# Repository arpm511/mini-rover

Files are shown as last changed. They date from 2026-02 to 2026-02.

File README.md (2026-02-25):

## Overview

A 6-wheel rocker-bogie rover featuring custom electronics and embedded control systems, built on the **Wild Willy** mechanical design originally created for the [DTU RoboCup](https://robocup.dtu.dk/) stair-climbing challenge.

This project focuses on developing advanced motor control algorithms, power management systems, and autonomous navigation capabilities using modern embedded systems and robotics frameworks.

The rocker-bogie suspension design, inspired by NASA's JPL Martian rovers, enables:
- Independent control of all six wheels
- In-wheel motor mounting for improved weight distribution
- Integrated cable management throughout the arm structure

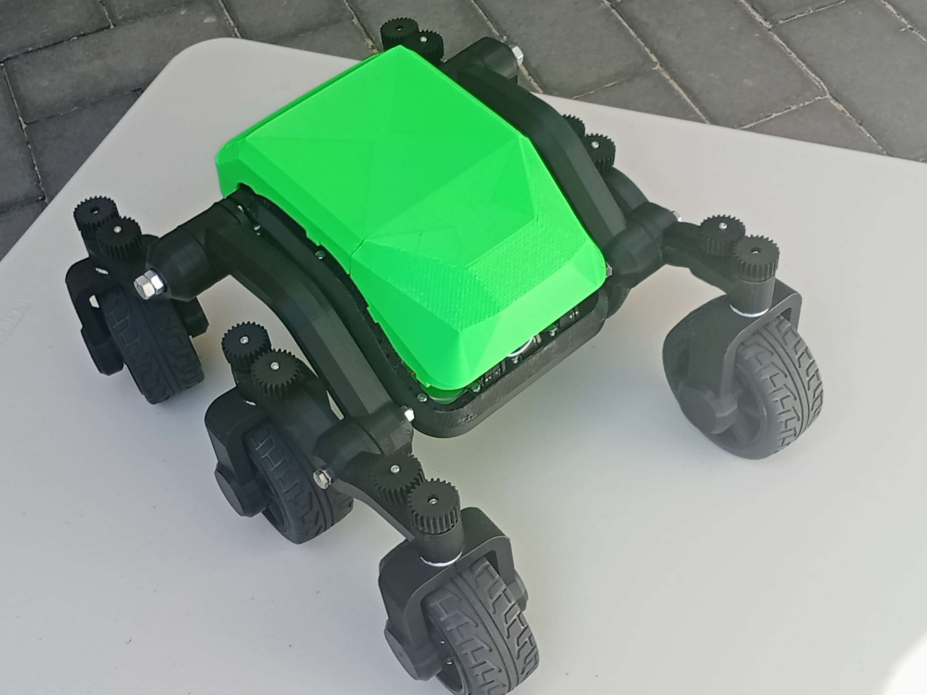
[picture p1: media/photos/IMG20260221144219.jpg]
mini rover photo1


### Project Scope & Attribution

**Original Mechanical Design**: [Wild Willy](https://robocup.dtu.dk/) - 3D printable rocker-bogie chassis, differential systems, and frame structure. The STL files are included in this repository for assembly reference.

**Custom Development Work**:
- **Electronics Design**: Motor driver circuits, power distribution, sensor integration
- **Embedded Software**: Arduino-based PID motor control, encoder feedback systems
- **Control Algorithms**: Speed regulation, differential steering implementation  
- **Future Development**: ROS2 integration for autonomous navigation and SLAM

The differential mechanism between the main arms is housed internally to maximize available mounting space. The frame features mounting points around the perimeter for expansion with additional sensors and systems.

> **Project Status**: Active development. Current implementation includes basic drive systems and manual control. Ongoing work focuses on closed-loop PID motor control and preliminary autonomous navigation capabilities.

## 3D Printing

Look at the file names to determine how many times you need to print each item (e.g 1x_1xm means print one time as-is and one time mirrored).

The largest part is the frame. If it is too large for your printer, consider placing it on the side and diagonally on the bed. An alternative is to split the mesh in two and this way it can also be printed without supports.

All of the parts were printed with the same settings, the only variable being the supports, which for some models are not required:

- Layer height 0.2mm
- Infill: 10%
- Material: PLA
- Printing temperature: Nozzle: 205, Plate: 60, Flow: 100%
- Speed: 80mm/s
- Supports: yes
- Build plate adhesion: Raft 

**Printing parts**

| Qty | Part | Supports | Est. time (per unit) | Total time | Preview | Qty | Part | Supports | Est. time (per unit) | Total time | Preview |
| --- | --- | --- | --- | --- | --- | --- | --- | --- | --- | --- | --- |
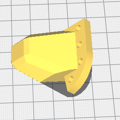
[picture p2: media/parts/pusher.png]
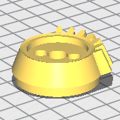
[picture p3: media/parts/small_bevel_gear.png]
| 1x_1xm | pusher | everywhere | 35mins | 1h10m |  | 1x_1xm | small bevel gear | everywhere | 56mins | 1h52m |  |
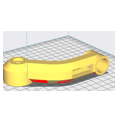
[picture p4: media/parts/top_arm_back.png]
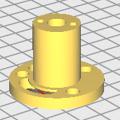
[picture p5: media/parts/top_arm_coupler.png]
| 1x_1xm | top arm back | touching buildplate | 4h40m | ~9h |  | 1x_1xm | Top arm coupler | everywhere | 1h2m | 2h4m |  |
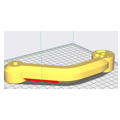
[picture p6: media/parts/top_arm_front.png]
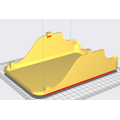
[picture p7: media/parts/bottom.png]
| 1x_1xm | top arm front | touching buildplate | 5h48m | ~12h |  | 1x | bottom | everywhere | 10h17mins | 10h17m |  |
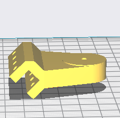
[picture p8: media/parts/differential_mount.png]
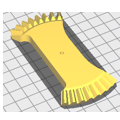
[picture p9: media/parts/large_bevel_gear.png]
| 1x | differential mount | everywhere | 1h28m | 1h28m |  | 1x | large bevel gear | everywhere | 1h24m | 1h24m |  |
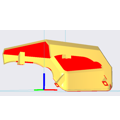
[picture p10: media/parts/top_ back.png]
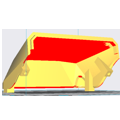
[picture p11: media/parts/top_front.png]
| 1x | top back | everywhere | 8h47m | 8h47m |  | 1x | top front | everywhere | 7h | 7h |  |
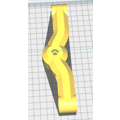
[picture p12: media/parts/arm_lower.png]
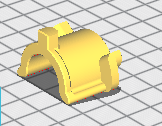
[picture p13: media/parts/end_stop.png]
| 2x | arm lower | touching buildplate | 5h20m | ~11h |  | 2x | end stop | everywhere | 44mins | ~1h30m |  |
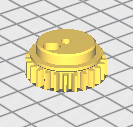
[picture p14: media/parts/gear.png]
| 6x | gear | everywhere | 29mins | 1h |  | 6x | gear servo | everywhere | 24mins | 2h27m |  |
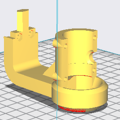
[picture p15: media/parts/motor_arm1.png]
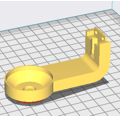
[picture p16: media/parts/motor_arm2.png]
| 6x | motor arm 1 | touching buildplate | 2h44m | 16h2m |  | 6x | motor arm 2 | touching buildplate | 1h43m | 10h2m |  |
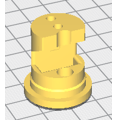
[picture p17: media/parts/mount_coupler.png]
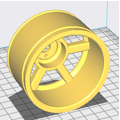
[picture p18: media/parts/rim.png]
| 6x | motor mount couplers | everywhere | 45m | 4h29m |  | 6x | rim | everywhere | 6h34m | ~40h |  |
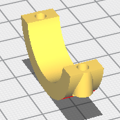
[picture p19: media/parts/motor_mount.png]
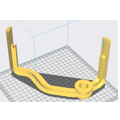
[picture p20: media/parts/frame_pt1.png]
| 12x | motor mount | everywhere | 25mins | 2h30m |  | 1x | frame pt1 | everywhere | 7h32m | 7h32m |  |
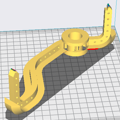
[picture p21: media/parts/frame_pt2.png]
| 1x | frame pt2 | everywhere | 5h48m | 6h9m |  |  |  |  |  | |  |
|  |  |  |  |  |  |  |  |  |  | Total | ~181h |

## Bill of materials

| Qty | Part | Buy | Price | Total Price |
| --- | --- | --- | --- | --- |
| 6x | 25GA370 DC 6V Micro Gear Motor, 130 RPM, 1:46:8 | [Buy](https://www.aliexpress.com/item/1005006213989239.html) | $10.19 | $68.14 |
| 6x | Servos: TGY-R5180MG | [Buy](https://www.aliexpress.com/item/1005001817755047.html) | $7.34 | $53 |
| 6x | Tires: BS701-002T (103mm )D, 72mm ID, 42mm width | [Buy](https://www.aliexpress.com/item/33042672599.html) | Price | Total Price |
| 1x | M8 Threaded Rod 285mm | [Buy](https://amzn.to/49huaWb) | Price | Total Price |
| 6x | 4mm Rigid flange coupling | [Buy](https://amzn.to/3PEXTBy) | Price | Total Price |
| 1x | Teensy 4.1 | [Buy](https://core-electronics.com.au/teensy-4-1-headers.html) | Price | Total Price |
| 1x | Raspberry Pi zero W | [Buy](https://amzn.to/3vCqAYT) | Price | Total Price |
| 1x | Rassperry PI W Zero camera | [Buy](https://amzn.to/4cGiFL0) | Price | Total Price |
| 1x | Signal wire | [Buy](https://amzn.to/3VGxy9L) | Price | Total Price |
| 1x | Power Wire | [Buy](https://amzn.to/49dfCXC) | Price | Total Price |
| 1x | Servo extension cables | [Buy](https://amzn.to/4axRzDK) | Price | Total Price |
| 1x | Metal glue | [Buy](https://amzn.to/3vyFaR6) | Price | Total Price |
| 3x | Makerverse motor driver (2 channel) | [Buy](https://core-electronics.com.au/makerverse-motor-driver-2-channel.html) | Price | Total Price |
| 1x | LiPo Battery | [Buy](https://amzn.to/3vCszwn) | Price | Total Price |
| 1x | Smart Charger | [Buy](https://amzn.to/3xpqFzy) | Price | Total Price |
| 1x | XT60 Connector | [Buy](https://amzn.to/3IYikWc) | Price | Total Price |
| 1x | DC Buck Converter | [Buy](https://amzn.to/4ayl34v) | Price | Total Price |
| 1x | M2 & M3 nuts and bolts assorted pack | [Buy]() | Price | Total Price |

Alternatives (replacements)

| Qty | Part | Buy | Price | Total Price |
| --- | --- | --- | --- | --- |
| 6x | Servos: DS041MG | Buy | Price | Total Price |
| 6x | Tires:  | [Buy](https://www.aliexpress.com/item/33042672599.html) | Price | Total Price |
| Qty | Tires: |[ Buy](https://www.aliexpress.com/item/1005003695930838.html) | Price | Total Price |
| 1x | Arduino Mega | [Buy](https://amzn.to/3PLritH) | Price | Total Price |
| 3x | Motor driver controller | [Buy](https://amzn.to/43F0xNb) | Price | Total Price |

## Schematics

- [diagram](./images/circuit_image.svg)
- [cirkit designer diagram](https://app.cirkitdesigner.com/project/dcd96944-0a77-4412-a378-ee0936a374ed)

### Power

- motor 450mA (450 x 6) = 2.7A
- servos 100-250 mA = (250 x 6) = 1.5A

- ~ 4.2A

## Assembly instructions

The robot can be fully assembled with M3 nuts and bolts. The arms are supported by long M8 threaded rod. The top lid attached with magnets. The fully assembled robot is about 430x330x220 mm (LxWxH)

[video here](https://www.youtube.com/watch?v=bXdt8hng2WM)

## Software & Control

### Arduino Sketches

Located in `src/Arduino/sketches/`:

- **Drive test** sketch that implements a basic crab steering mode
- **pid_control**: PID control implementation for JGA25-370 motors with encoder feedback
- Additional sketches for various control modes (in development)
- Tests sketches to verify correct operation of the actuators (servos, motors)

### Getting Started with Code

1. Install [Arduino IDE](https://www.arduino.cc/en/software) or [PlatformIO](https://platformio.org/)
2. Connect your Arduino board
3. Open the desired sketch from `src/Arduino/sketches/`
4. Adjust pin definitions to match your wiring
5. Upload and test

### ROS Integration (Planned)

- Autonomous navigation
- Vision-based obstacle detection
- SLAM capabilities

## Project Status

- ✅ Mechanical design and 3D models
- ✅ Basic drive system
- 🚧 PID motor control (in development)
- 🚧 ROS integration (planned)
- 📋 Autonomous stair climbing (planned)

## Contributing

Contributions are welcome! Please read [CONTRIBUTING.md](CONTRIBUTING.md) for guidelines on how to contribute to this project.

## License

- **Software**: MIT License - see [LICENSE](LICENSE)
- **Hardware**: Creative Commons Attribution-ShareAlike 4.0 International License

## Acknowledgments

- **Wild Willy** - Original rocker-bogie mechanical design and 3D printable chassis
- **DTU RoboCup** - Competition framework that inspired the original design
- **NASA JPL** - Rocker-bogie suspension concept from Martian rover programs

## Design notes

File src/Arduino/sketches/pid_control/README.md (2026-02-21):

# PID Motor Control for JGA25-370

This Arduino sketch implements PID (Proportional-Integral-Derivative) control for the JGA25-370 DC geared motor with integrated magnetic hall encoder.

## Features

- ✅ Real-time speed control in RPM
- ✅ Encoder-based feedback for precision
- ✅ Serial interface for tuning and monitoring
- ✅ Anti-windup protection
- ✅ Runtime PID parameter adjustment

## Hardware Requirements

### Components
- **Motor**: JGA25-370 DC motor with encoder (6V version recommended)
- **Motor Driver**: L298N, TB6612FNG, or similar H-bridge driver
- **Controller**: Arduino Nano, Uno, or Mega
- **Power Supply**: 6V for motor (separate from Arduino if high current)

### Wiring Diagram

```
Arduino          Motor Driver        JGA25-370 Motor
-------          ------------        ---------------
Pin 9 (PWM) ---> ENA/PWMA            
Pin 8       ---> IN1             
Pin 7       ---> IN2             
                 OUT1 ------------> Motor +
                 OUT2 ------------> Motor -
                 
Pin 2 (INT) <--- Encoder A (Yellow)
Pin 3 (INT) <--- Encoder B (White)
GND         <--- Encoder GND (Black)
5V          <--- Encoder VCC (Red)
```

### Notes on Wiring
- Connect encoder to 5V (not motor voltage!)
- Use interrupt-capable pins for encoder (pins 2 & 3 on Arduino Uno/Nano)
- Ensure common ground between Arduino and motor driver
- Add 100nF capacitor across motor terminals to reduce noise

## Software Setup

1. **Install Arduino IDE** (1.8.x or 2.x)

2. **Open the sketch**
   ```
   File > Open > pid_control/pid_control.ino
   ```

3. **Configure pins** (if different from defaults)
   ```cpp
   const int MOTOR_PWM = 9;
   const int MOTOR_DIR1 = 8;
   const int MOTOR_DIR2 = 7;
   const int ENCODER_A = 2;
   const int ENCODER_B = 3;
   ```

4. **Set motor parameters**
   ```cpp
   const int ENCODER_PPR = 12;        // Pulses per revolution
   const float GEAR_RATIO = 46.8;     // Check your motor specs!
   ```

5. **Upload to Arduino**
   - Select your board: `Tools > Board > Arduino Nano/Uno`
   - Select port: `Tools > Port > /dev/ttyUSB0` (or COM port on Windows)
   - Click Upload

## Usage

### Serial Monitor

Open Serial Monitor at **115200 baud**

### Commands

| Command | Description | Example |
|---|---|---|
| `S<rpm>` | Set target speed in RPM | `S100` - Set 100 RPM |
| `P<value>` | Set Kp (proportional gain) | `P2.5` |
| `I<value>` | Set Ki (integral gain) | `I5.0` |
| `D<value>` | Set Kd (derivative gain) | `D1.2` |
| `X` | Stop motor | `X` |
| `?` | Show help | `?` |

### Example Session

```
JGA25-370 PID Control Initialized
Commands: S<rpm> - Set speed, P<val> I<val> D<val> - Tune PID

> S50
Setpoint: 50.00 RPM

Setpoint: 50.00 | Speed: 12.45 | Error: 37.55 | Output: 75 | Count: 142
Setpoint: 50.00 | Speed: 34.21 | Error: 15.79 | Output: 68 | Count: 387
Setpoint: 50.00 | Speed: 48.92 | Error: 1.08 | Output: 52 | Count: 621
Setpoint: 50.00 | Speed: 50.15 | Error: -0.15 | Output: 50 | Count: 845

> S0
Setpoint: 0.00 RPM

> X
Motor stopped
```

## PID Tuning

### Default Parameters
```cpp
Kp = 2.0;   // Proportional gain
Ki = 5.0;   // Integral gain  
Kd = 1.0;   // Derivative gain
```

These values are based on research for the JGA25-370 motor and should provide a good starting point.

### Tuning Process

1. **Start with defaults**
   - Upload sketch and set a moderate speed (e.g., S50)
   - Observe behavior in Serial Monitor

2. **If motor oscillates** (speed bounces up and down)
   - Reduce Kp: `P1.5`
   - Or reduce Ki: `I3.0`

3. **If motor is sluggish** (slow to reach target)
   - Increase Kp: `P3.0`
   - Check for mechanical resistance

4. **If steady-state error** (doesn't quite reach target)
   - Increase Ki: `I7.0`
   - Be careful of integral windup

5. **To reduce overshoot**
   - Increase Kd: `D2.0`
   - Or reduce Kp slightly

### Ziegler-Nichols Method (Advanced)

1. Set Ki and Kd to 0: `I0`, `D0`
2. Gradually increase Kp until oscillations occur
3. Note the critical gain (Ku) and oscillation period (Tu)
4. Calculate:
   - Kp = 0.6 * Ku
   - Ki = 1.2 * Ku / Tu
   - Kd = 0.075 * Ku * Tu

## Troubleshooting

### Motor doesn't move
- ✓ Check wiring connections
- ✓ Verify motor driver power supply
- ✓ Check direction pins are correctly connected
- ✓ Try higher PWM values directly

### Encoder count not changing
- ✓ Check encoder wiring (especially VCC and GND)
- ✓ Verify encoder channels on interrupt pins
- ✓ Check for loose connections
- ✓ Test encoder signals with oscilloscope/multimeter

### Speed reading is wrong
- ✓ Verify ENCODER_PPR and GEAR_RATIO constants
- ✓ Check encoder connections
- ✓ Ensure SAMPLE_TIME is appropriate (100ms default)
- ✓ Look for electrical noise (add capacitors)

### Motor oscillates wildly
- ✓ Reduce Kp gain
- ✓ Reduce Ki gain
- ✓ Check for mechanical binding
- ✓ Verify PWM frequency is appropriate

### Encoder noise
- ✓ Add 100nF capacitor across motor terminals
- ✓ Use shielded cables for encoder wires
- ✓ Keep encoder wires away from motor wires
- ✓ Consider adding a Kalman filter (see docs)

## Performance Expectations

With proper tuning, you should achieve:
- **Accuracy**: ±2% of target speed
- **Rise time**: 1-2 seconds to target speed
- **Overshoot**: <10%
- **Steady-state error**: <1 RPM

## Advanced Features (TODO)

- [ ] Kalman filter for noise reduction
- [ ] Multiple motor coordination
- [ ] Position control mode
- [ ] Velocity profiling (acceleration/deceleration curves)
- [ ] EEPROM storage of PID parameters
- [ ] Auto-tuning algorithm

## References

- [JGA25-370 Motor Specifications](../../../parts/25GA370_dc_geared_motor/)
- [PID Control Theory](../../../docs/jga25-370_pid_control.md)
- [L298N Motor Driver Guide](../../../parts/L298N_motor_driver/)

## Contributing

Found a bug or have an improvement? Please open an issue or submit a pull request!

## License

MIT License - see [LICENSE](../../../LICENSE) for details

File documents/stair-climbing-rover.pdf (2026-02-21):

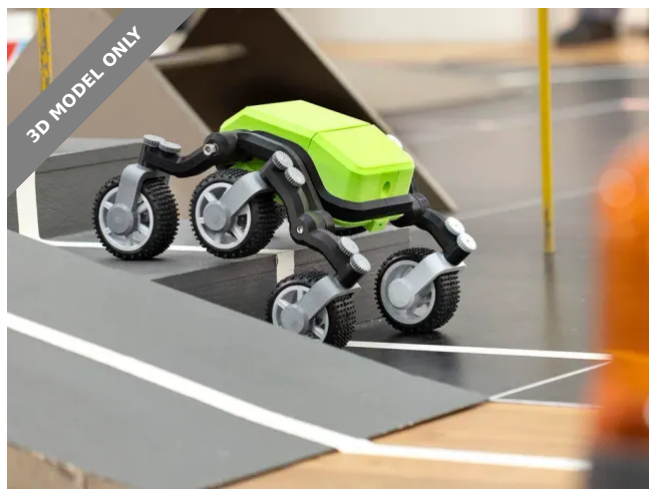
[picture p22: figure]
3D MODEL ONLY

## Summary

Rover was made specifically to do stair climbing. It is built on a rocker-bogie design, making this quite easy.

Hobby & Makers (https://printables.com/model?categoryId=48) > RC & Robotics (https://printables.com/model?categoryId=64)

Tags: thingiverse

My robot from the Danish DTU RoboCup (https://robocup.dtu.dk/) competition. The rover was made specifically to solve the stair climbing obstacle. It is built on a rocker-bogie design, making the stair climbing quite easy. See the videos of the robot in the competition below.

It was inspired by the great design of this Martian Rover. (https://www.thingiverse.com/thing:1318414) It is however redrawn completely in order to make it possible to turn all wheels separately. Also, I wanted the motors to be inside the wheels, and all wires to be hidden inside the arms. The differential between the two main arms is inside the enclosure to keep the top free for future additions. The main frame has mounting holes all the way around making it easy to mount things inside the enclosure.

The design here is missing a few details, like the mount for the camera and a Raspberry Pi. I assume that if anyone want to make this, they will adopt these features for their own needs.

WildWilly (https://printables.com/@WildWilly_266538)

## Stair Climbing Rover

VIEW IN BROWSER (https://printables.com/model/194299-stair-climbing-rover)

updated 30. 10. 2024 | published 30. 10. 2024

The robot is assembled mostly with M3 nuts and bolts. The arms are supported by a long M8 threaded rod. The top lid attaches with magnets. The fully assembled robot is about 430x330x220 mm (LxWxH).

Motors: 25GA370 DC 6V Micro Gear Motor, 130RPM, 1:46.8 Couplers: Chihai Motor 4 mm Rigid Flange Coupling
Servos: TGY-R5180MG. An alternative is DS041MG which should fit, but requires a different gear. See this comment. (https://www.printables.com/model/194299-stair-climbing-rover/comments/2139935)
Tires: BS701-002T (103 mm OD, 72 mm ID, 42 mm width). Alternatively @elpidiovaldez_18382 found that this (https://www.aliexpress.com/item/33042672599.html) or this (https://www.aliexpress.com/item/1005003695930838.html) can be used as a direct replacement. Look in the comments section (https://www.printables.com/model/194299-stair-climbing-rover/comments/871660) for more details:

Note that the servos I used may be a bit under powered if used in rough terrain. On smooth surfaces they are sufficient.

For some accessories see this collection. (https://www.printables.com/social/266538-wildwilly/collections/167873)

If you like this model, please consider also downloading it from Maker World. (https://makerworld.com/en/models/207575#profileId-233818) It will bring me a little close to to getting some free filament for future projects.

If you make remixes of this model and publicly shares the modifications, please consider uploading your changes in an editable format like STEP. It makes it so much easier for others to improve on your changes.
Printing

Look at the filenames to determine how many times you need to print each item.
1x_1xm_ means print one time as-is and one time mirrored.

The largest part is the frame. If it is too large for your printer, you can most likely print it by putting it on the side, and placing it diagonally on the bed. Also, cut it in two, like I did in the assembly video. That way it can be printed without support.
Outdoor TestAssembly InstructionsThe Rover in the Competition

First version going up the stairs:

Second version. Unfortunately the wooden floor was slippery, so the robot couldn't go up the stairs. Instead, it took a trip to the seesaw:

•
•
•

•

## Model files

- Step | 20 files

2x_arm_lower.step

1x_bottom.step

1x_large_bevel_gear.step

1x_1xm_pusher.step

1x_top_front.step

1x_top_back.step

12x_motor_mount.step

1x_1xm_top_arm_coupler.step

6x_motor_arm2.step

6x_rim.step

1x_1xm_top_arm_back.step

1x_frame.step

6x_motor_arm1.step

2x_end_stop.step

1x_differential_mount.step

1x_1xm_top_arm_front.step

1x_1xm_small_bevel_gear.step

6x_motor_mount_coupler.step

6x_gear.step

6x_gear_servo.step

1x_1xm_top_arm_front.stl

1x_1xm_top_arm_back.stl

2x_arm_lower.stl

2x_end_stop.stl

1x_1xm_top_arm_coupler.stl

1x_frame.stl

1x_bottom.stl

1x_top_back.stl

1x_top_front.stl

6x_rim.stl

6x_motor_arm1.stl

6x_motor_arm2.stl

12x_motor_mount.stl

6x_motor_mount_coupler.stl

1x_1xm_small_bevel_gear.stl

1x_large_bevel_gear.stl

1x_differential_mount.stl

## License

This work is licensed under a
Creative Commons (4.0 International License)

Attribution (http://creativecommons.org/licenses/by/4.0/)

✖ | Sharing without ATTRIBUTION
✔ | Remix Culture allowed
✔ | Commercial Use
✔ | Free Cultural Works
✔ | Meets Open Definition

1x_1xm_pusher.stl

6x_gear_servo.stl

6x_gear.stl

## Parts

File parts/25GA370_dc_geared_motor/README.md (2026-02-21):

# 25GA370 DC Geared Motor

<!--Write a short description describing the purpose of the SOP package.-->

## Table of Contents

- [dimensions](#dimensions)
- [specification](#specification)
- [interface definition](#interface-definition)
- [pinout](#pinout)
- [hookup guide](#hookup-guide)

## Dimensions

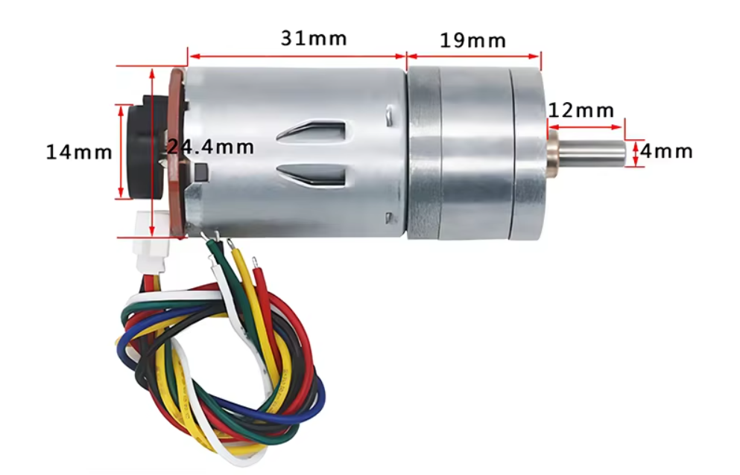
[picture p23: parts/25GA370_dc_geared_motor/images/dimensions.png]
dimensions


## Specification

<!--Write the specification of the sensor or actuator.
Also include links to the datasheet and manuals.-->

- **Motor Type:** Brushed DC Motor
- **Encoder Type:** Quadrature Encoder
- **Supply Voltage:** Typically 6V to 12V DC
- **Rated Speed:** Varies, e.g., 1000 RPM at 12V
- **Rated Torque:** Varies, e.g., 1 Nm at 12V
- **Gear Ratio:** Often included, e.g., 50:1

## Interface definition

<!--Create a table with the pinout of the sensor or actuator.
Include the pin number, signal name, signal type, and signal description.-->

| Pin | Name | Type | Description |
| --- | --- | --- | --- |
| Motor - (white) | Motor GND | Power | motor ground |
| Encoder - (black) | Encoder GND | Power | encoder ground |
| Enable A (yellow) | Enable Motor A | digital | output pulses for speed/position |
| Enable B (green) | Enable Motor B | digital | output pulses for direction |
| Encoder + (blue) | Encoder 3.3V/5V | Power | encoder Vin |
| Motor + (red) | Motor Vin | Power | motor vc |

## Pinout

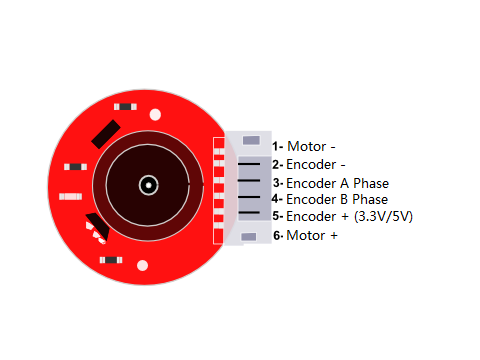
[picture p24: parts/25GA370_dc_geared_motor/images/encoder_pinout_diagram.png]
encoder pinout


## Hookup guide

<!--Describe how to connect the sensor or actuator to the microcontroller or processor.-->

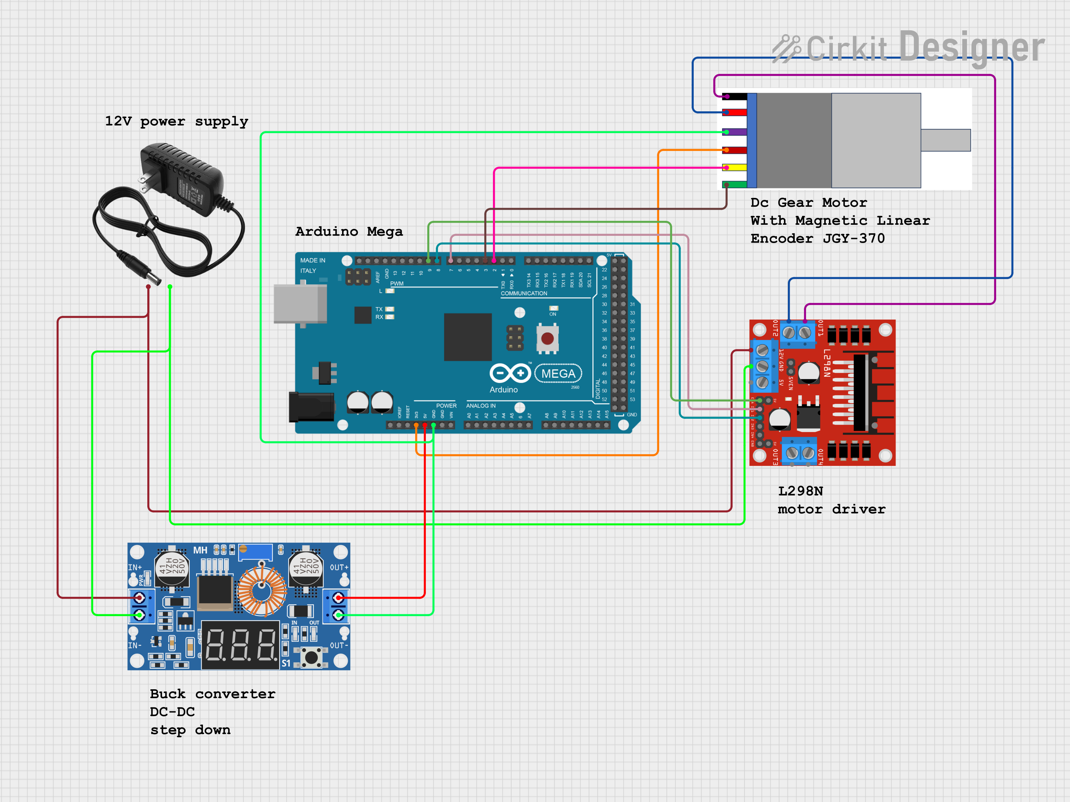
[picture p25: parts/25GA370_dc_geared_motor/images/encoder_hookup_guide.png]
encoder hookup guide


## Installation

<!--Describe how to install the software required to use the sensor or actuator.-->

1. Connect the motor power pins to the your power supply, ensuring the voltage is within the motor's rated specifications.
2. Connect the encoder VCC to a 3.3V or 5V power supply from your microcontroller (e.g. Arduino UNO).
3. Connect the encoder GND to the ground of your microcontroller.

Notes:
- Ensure the power supply does not exceed the motor's voltage rating to prevent damage.
- Use a motor driver or H-bridge to control the motor's direction and speed.
- Implement debounce logic in software or hardware to ensure accurate encoder readings.
- Consider using a pull-up or pull-down resistor on the encoder outputs to stabilize the signal.

## Usage

<!--Include a simple example of how to use the sensor or actuator.-->

To use the motor with an Arduino UNO, you'll need to connect the encoder output pins to two digital input pins on the Arduino. You can use the `attachInterrupt` function to count the pulses from the encoder - these represent the motor's rotation.

```c++
// Define the encoder pins
const int encoderPinA = 2; // Interrupt pin for encoder A
const int encoderPinB = 3; // Interrupt pin for encoder B

volatile long encoderTicks = 0;

// Interrupt service routine for encoder A
void encoderISR() {
  if (digitalRead(encoderPinB) == HIGH) {
    encoderTicks++;
  } else {
    encoderTicks--;
  }
}

void setup() {
  pinMode(encoderPinA, INPUT);
  pinMode(encoderPinB, INPUT);
  // Attach interrupt on a rising edge of encoder A (to call encoderISR)
  attachInterrupt(digitalPinToInterrupt(encoderPinA), encoderISR, RISING);
  Serial.begin(9600);
}

void loop() {
  Serial.println(encoderTicks);
  delay(1000); // Update every second
}
```

## Resources

<!--Include links to the datasheet, manuals, and other resources.-->

- [docs.cirkitdesigner.com](https://docs.cirkitdesigner.com/component/727f690f-5a57-4c09-b784-5f667e6d6b6b/dc-motor-with-encoder)

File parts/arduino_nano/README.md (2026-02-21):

https://www.makerguides.com/arduino-nano/

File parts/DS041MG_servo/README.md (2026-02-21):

# GDW DS031MG Servo

<!-- Short description -->

The GDW DS031MG is a digital metal gear micro servo commonly used in RC helicopters and airplanes. The operating frequency of 1520 microseconds (µs) corresponds to a pulse repetition rate of approximately 333 Hz, which is standard for many servos. This means the servo expects a control signal every 1520 µs

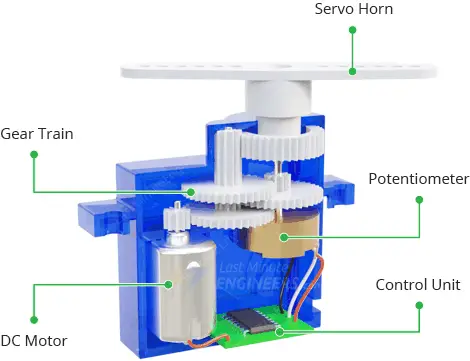
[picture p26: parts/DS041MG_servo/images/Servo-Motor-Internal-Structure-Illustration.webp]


## Table of Contents

- [dimensions](#dimensions)
- [specification](#specification)
- [interface definition](#interface-definition)
- [pinout](#pinout)
- [hookup guide](#hookup-guide)
- [installation](#installation)
- [usage](#usage)
- [resources](#resources)

## Dimensions

- Length: 23mm
- Width: 12.2mm
- Height: 29mm
- Weight: 16g

## Specification
<!-- Also include links to the datasheet and manuals. -->

- **Operating Voltage Range**: 4.8V up to 6.0V
- **Operating Temperature Range**: -20C up to +60C
- **Working Frequency**: 1520us/333Hz
- **Dead Bandwidth**: 3usecs
- **Motor Type**: DC motor
- **Chip Type**: digital
- **Gear material**: copper
- **Horn gear spline**: 25T 4.9mm
- **Wire length**: 170 +/- 5mm

Bench tests

| Test voltage | 4.8V | 6.0V |
| --- | --- | --- |
| Speed | 0.12sec/60deg | 0.10sec/60deg |
| Torque | 2.5kg.cm | 3kg.cm |

## Interface definition

<!-- Create a table with the pinout of the sensor or actuator.
Include the pin number, signal name, signal type, and signal description -->

| Pin | Signal | Type | Description | 
| --- | --- | --- | --- |
| Black | GND | Power | pwm ground signal |
| Yellow | PWM | analog | pwm signal pin |
| Red | 6v | power | 6 pwm power signal |

## Pinout
Servo Wire Colors

Standard 3-pin servo connector:
- Brown/Black: Ground
- Red: Power (4.8-6V)
- Yellow/Orange: Signal (PWM)

## Hookup guide

1. Connect the brown/black wire to GND on your microcontroller
2. Connect the red wire to 5V power supply
3. Connect the yellow/orange wire to a PWM capable pin on your microcontroller
4. Ensure power supply can provide enough current (>500mA recommended)

## Installation

No special libraries required for basic Arduino control. For advanced control, you can use:
1. Install Arduino IDE
2. (Optional) Install Servo library:
   - Already included with Arduino IDE
   - Or go to Sketch -> Include Library -> Servo

Given the specs, here's the more specific **PWM signal range** you'll need to control this servo:

- **Pulse width for 0°**: Around **1000 µs** (may vary slightly, but this is typical for most servos).
- **Pulse width for 90°**: Around **1520 µs** (this should be the center position based on your spec).
- **Pulse width for 180°**: Around **2000 µs**.

### Adjusting PWM Frequency:
Since the working frequency is **333 Hz**, this translates to a **3 ms period** (3000 µs per cycle). If you're using the standard **Arduino Servo library**, it typically operates at **50 Hz**, which results in a 20 ms period (20000 µs). Since this servo is designed for **333 Hz**, you may need to use a different library or adjust the PWM frequency.

Here’s an example of how you can adjust the PWM frequency and control the servo using the **Teensy** platform:

## Usage

```c++
#include <PWMServo.h>

const int servoPin = 9;  // Pin where the servo is connected

void setup() {
  pinMode(servoPin, OUTPUT);
  
  // Initialize PWM on the specified pin with a frequency of 333 Hz
  pwm_begin();
  pwm_set_frequency(servoPin, 333);  // Set PWM frequency to 333 Hz
  
  // Position the servo at 90 degrees (center position, 1520 µs pulse)
  pwm_write(servoPin, 1520);  // 1520 µs pulse for center (90 degrees)
}

void loop() {
  // Move the servo to 0 degrees (1000 µs)
  pwm_write(servoPin, 1000);  // 1000 µs pulse for 0 degrees
  delay(1000);  // Wait for 1 second

  // Move the servo to 90 degrees (1520 µs)
  pwm_write(servoPin, 1520);  // 1520 µs pulse for 90 degrees
  delay(1000);  // Wait for 1 second

  // Move the servo to 180 degrees (2000 µs)
  pwm_write(servoPin, 2000);  // 2000 µs pulse for 180 degrees
  delay(1000);  // Wait for 1 second
}
```

## Resources
- [Servo Library Reference](https://www.arduino.cc/reference/en/libraries/servo/)
- [PWM Control Tutorial](https://learn.sparkfun.com/tutorials/pulse-width-modulation)
- [Servo Motor Basics](https://learn.adafruit.com/adafruit-arduino-lesson-14-servo-motors)

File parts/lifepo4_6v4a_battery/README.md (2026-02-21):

# Powertech 6.4V 4.5Ahm LiFePO4 battery

<!-- Short description -->

They’re actually made up of regular 18650 LiFePO4 cells, which are in mass production for many portable devices. An internal battery management system (BMS) ensures all cells are uniformly charged and discharged, as well as providing short circuit, over current, and reverse polarity protection. This provides you with a higher degree of protection than a traditional lead acid battery which is unprotected, and can discharge rapidly under short circuit conditions, causing fire and damage. The internal BMS will also limit discharge and manage cut-off voltage, to further protect the internal cells. 

This 5Ah model can provide continuous current up to 4.5A with peaks of 9A. Absolutely perfect for portable power, and replacement of similar capacity lead acid / AGM battery. Also often found in alarm systems, and other critical systems with backup batteries.

## Table of Contents

- [dimensions](#dimensions)
- [specification](#specification)
- [interface definition](#interface-definition)
- [pinout](#pinout)
- [hookup guide](#hookup-guide)
- [installation](#installation)
- [usage](#usage)
- [resources](#resources)

## Dimensions

- Length: 70mm
- Width: 35mm
- Height: 100mm
- Weight: 280g

## Specification

- **Battery Chemistry:** LiFePO4 (Lithium Iron Phosphate)
- **Nominal Voltage:** 6.4V
- **Capacity:** 4.5Ah
- **Max Continuous Discharge:** 4.5A
- **Peak Discharge:** 9A
- **Cycle Life:** >2000 cycles
- **Operating Temperature:** -20°C to 60°C
- **Charging Temperature:** 0°C to 45°C
- **Built-in Protection:** Short circuit, over-current, over-discharge
- **Charging Voltage:** 7.2V ±0.2V
- **Cut-off Voltage:** 5.0V

## Interface definition

| Terminal | Type | Description |
|---|---|---|
| Positive (+) | Power | Red terminal, 6.4V nominal output |
| Negative (-) | Power | Black terminal, ground connection |

## Hookup guide

1. Always observe correct polarity (red = positive, black = negative)
2. Use appropriate gauge wire for current draw (recommended: 18 AWG for <5A)
3. Ensure secure connections to prevent voltage drops
4. Add an inline fuse (5A recommended) for additional protection

## Installation

No software required. Hardware installation tips:
1. Mount battery securely to prevent movement
2. Ensure adequate ventilation
3. Keep away from heat sources
4. Use proper connectors rated for current

## Usage

**Charging:**
- Use only LiFePO4 compatible chargers
- Maximum charging voltage: 7.2V
- Recommended charging current: 2.25A (0.5C)

**Monitoring:**
```c++
// Basic voltage monitoring example
const int BATTERY_PIN = A0;
const float VOLTAGE_DIVIDER_RATIO = 2.0; // Adjust based on your voltage divider

void setup() {
  Serial.begin(9600);
  pinMode(BATTERY_PIN, INPUT);
}

void loop() {
  float voltage = (analogRead(BATTERY_PIN) * 5.0 * VOLTAGE_DIVIDER_RATIO) / 1024.0;
  Serial.print("Battery Voltage: ");
  Serial.println(voltage);
  delay(1000);
}
```

## Resources
- [jaycar store page](https://www.jaycar.com.au/6-4v-4-5ah-lithium-deep-cycle-battery/p/SB2200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)
- [LiFePO4 Charging Guide](https://batteryuniversity.com/learn/article/charging_lithium_iron_phosphate)
- [Safety Datasheet](https://www.jaycar.com.au/medias/SB2200-datasheet.pdf)

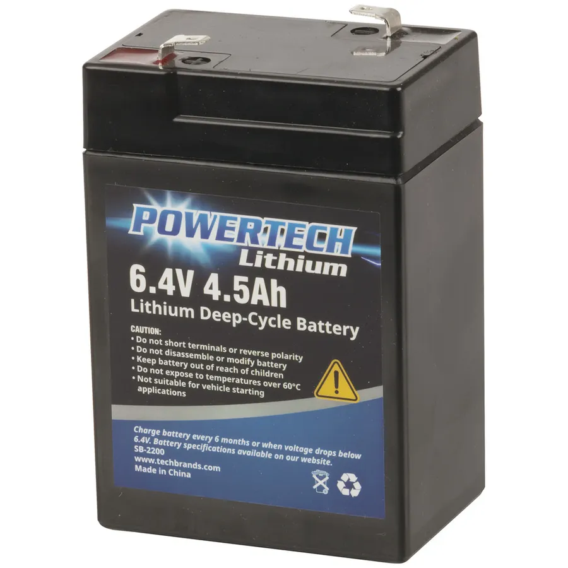
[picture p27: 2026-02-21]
parts/lifepo4_6v4a_battery/images/SB2200_6-4v-4-5ah-lithium-deep-cycle-battery_88462.webp

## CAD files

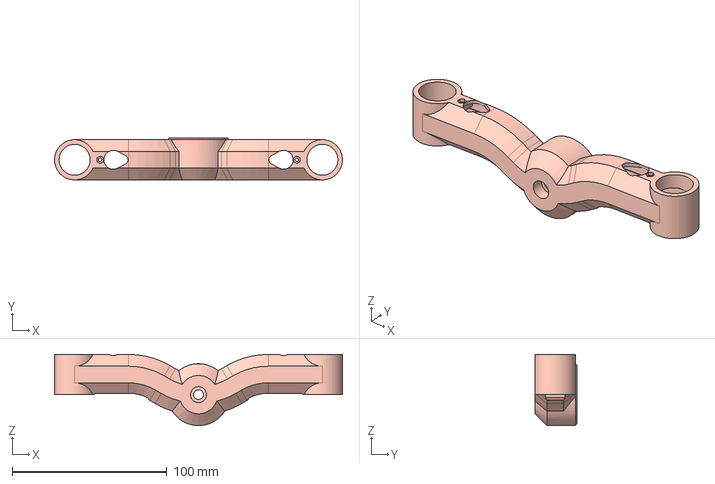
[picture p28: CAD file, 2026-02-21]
description/models/step/2x_arm_lower.step
186.0 x 27.0 x 46.0 mm

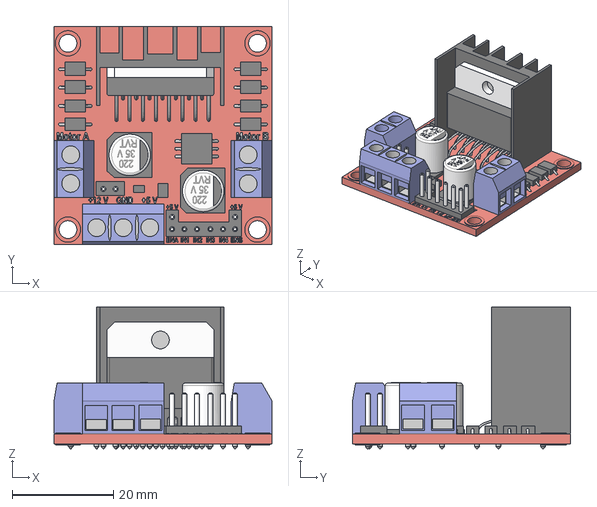
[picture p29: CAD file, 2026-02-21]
description/models/step/L298N_.step
43.0 x 43.0 x 28.0 mm

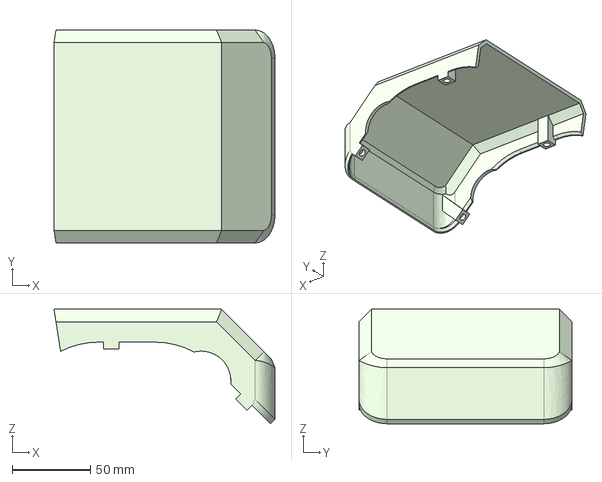
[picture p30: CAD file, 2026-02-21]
description/models/step/1x_top_back.step
141.0 x 135.8 x 73.1 mm

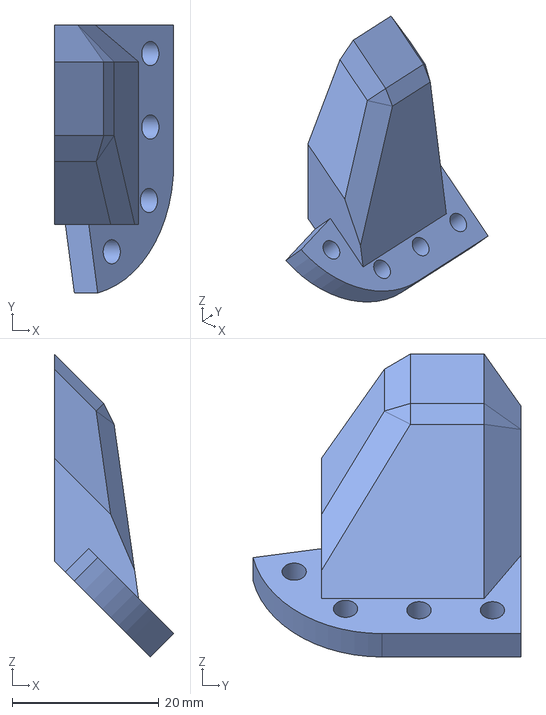
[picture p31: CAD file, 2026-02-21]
description/models/step/1x_1xm_pusher.step
16.3 x 36.5 x 41.2 mm

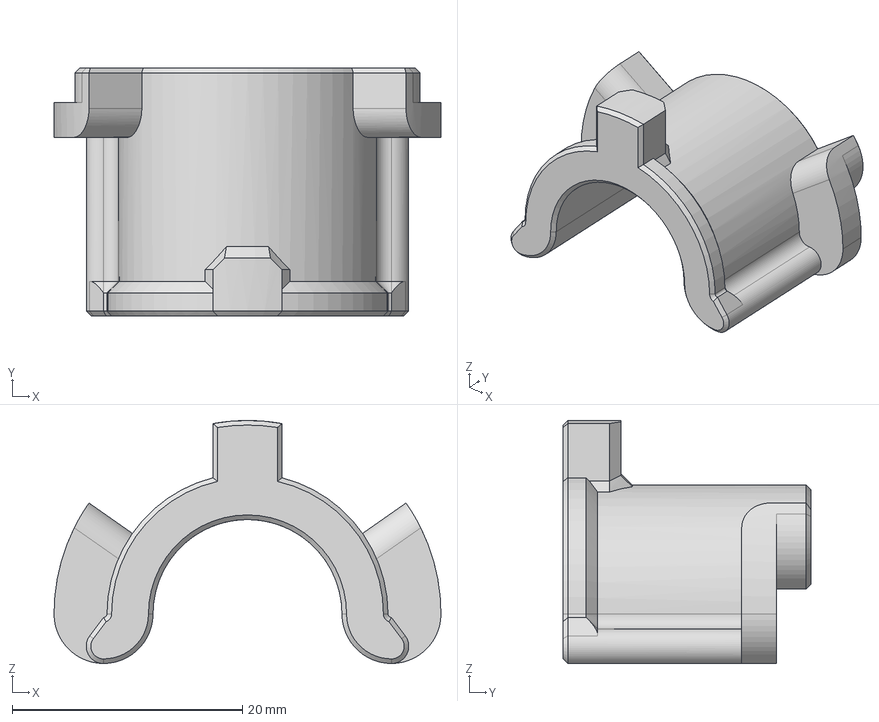
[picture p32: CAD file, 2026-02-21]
description/models/step/2x_end_stop.step
33.6 x 21.5 x 21.1 mm

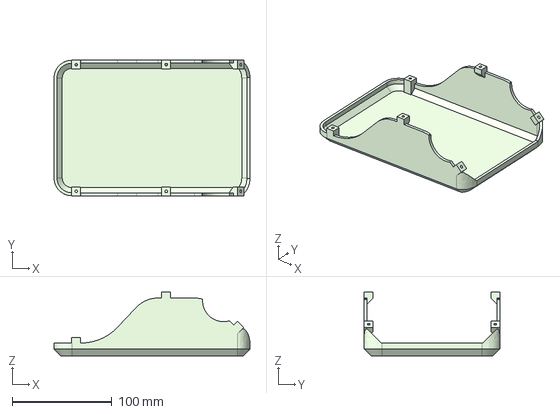
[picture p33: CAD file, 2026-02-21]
description/models/step/1x_bottom.step
196.4 x 135.8 x 64.1 mm

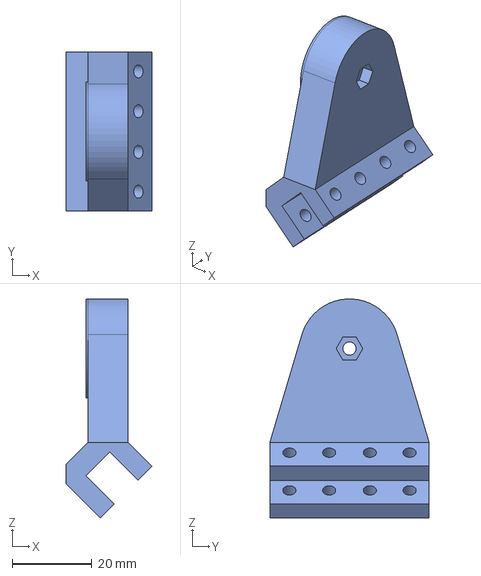
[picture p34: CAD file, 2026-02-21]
description/models/step/1x_differential_mount.step
21.5 x 40.0 x 55.0 mm

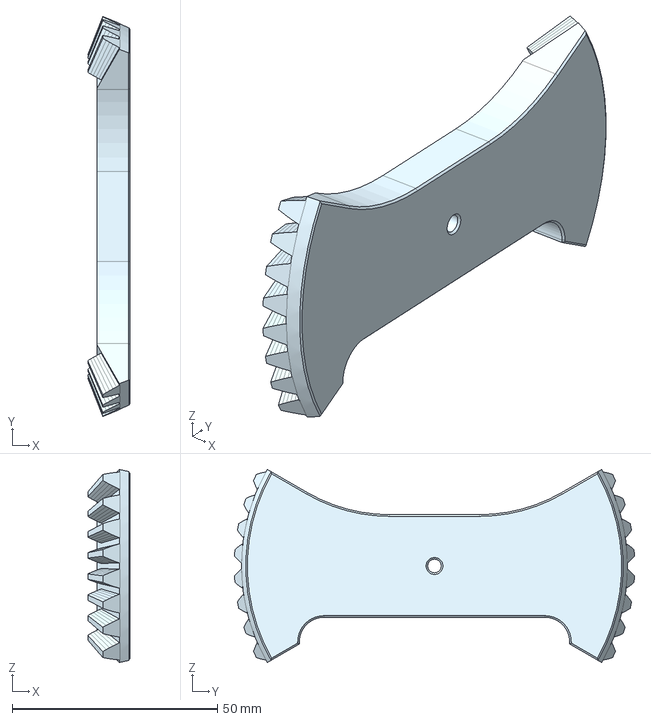
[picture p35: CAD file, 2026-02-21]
description/models/step/1x_large_bevel_gear.step
10.3 x 97.4 x 47.0 mm

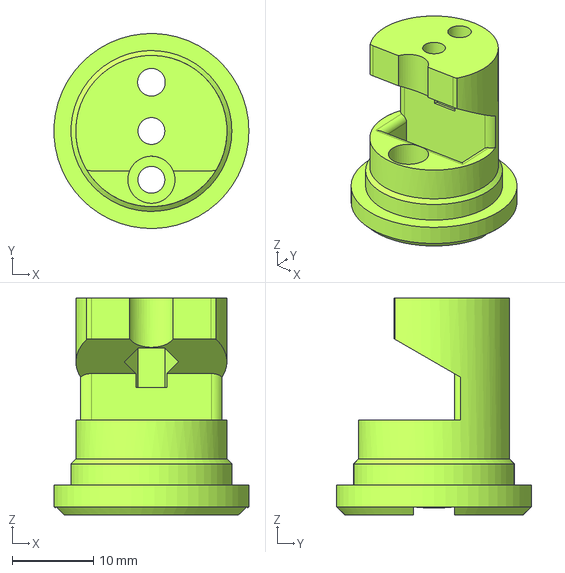
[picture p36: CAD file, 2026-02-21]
description/models/step/6x_motor_mount_coupler.step
24.0 x 24.0 x 26.7 mm

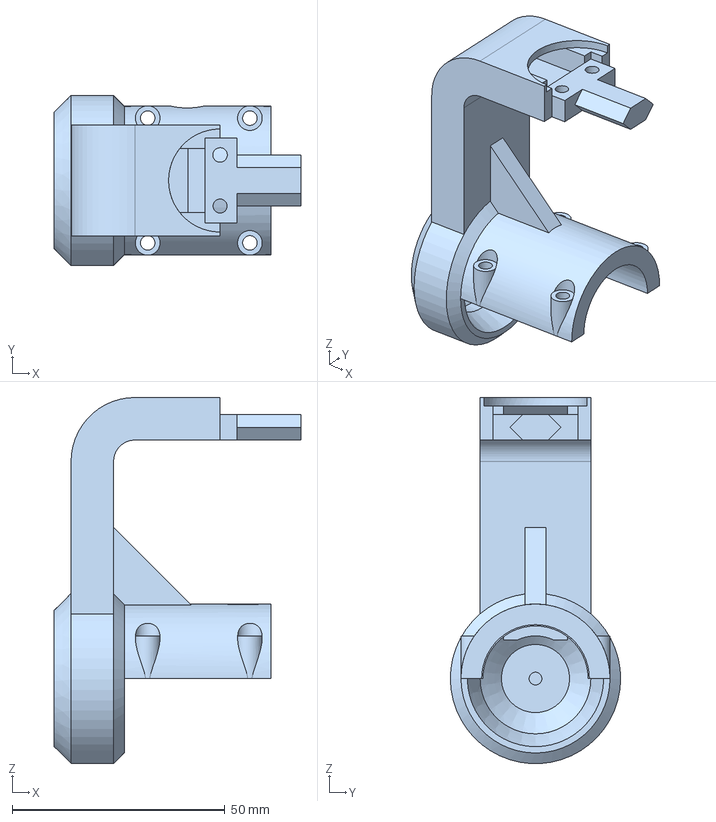
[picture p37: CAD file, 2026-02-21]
description/models/step/6x_motor_arm1.step
58.0 x 40.0 x 86.0 mm

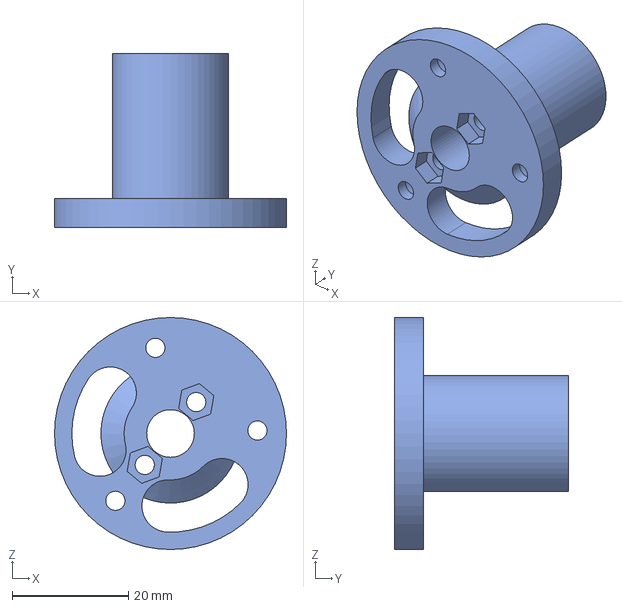
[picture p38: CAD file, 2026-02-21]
description/models/step/1x_1xm_top_arm_coupler.step
40.0 x 30.0 x 40.0 mm

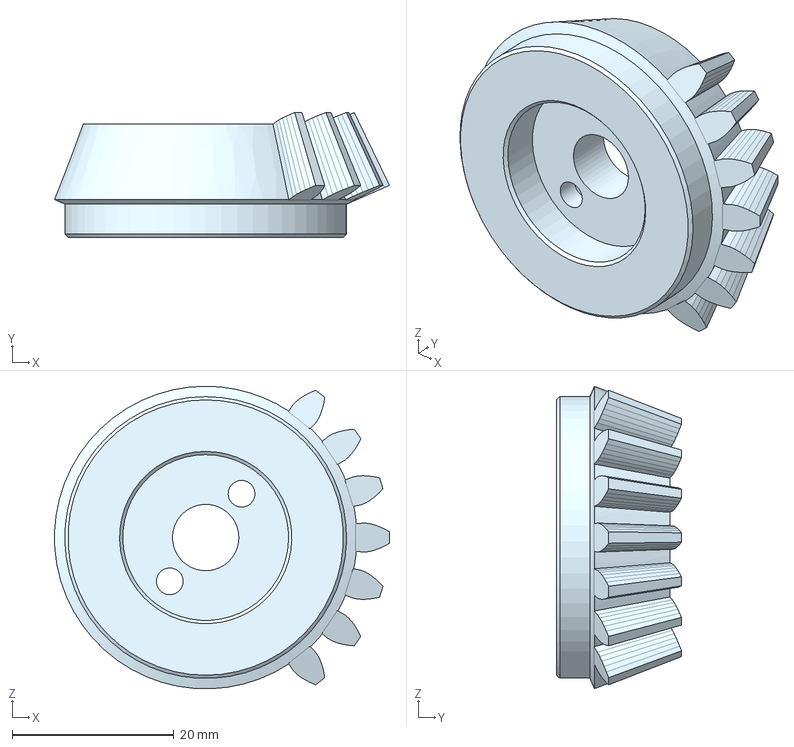
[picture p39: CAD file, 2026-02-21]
description/models/step/1x_1xm_small_bevel_gear.step
41.4 x 15.5 x 37.4 mm

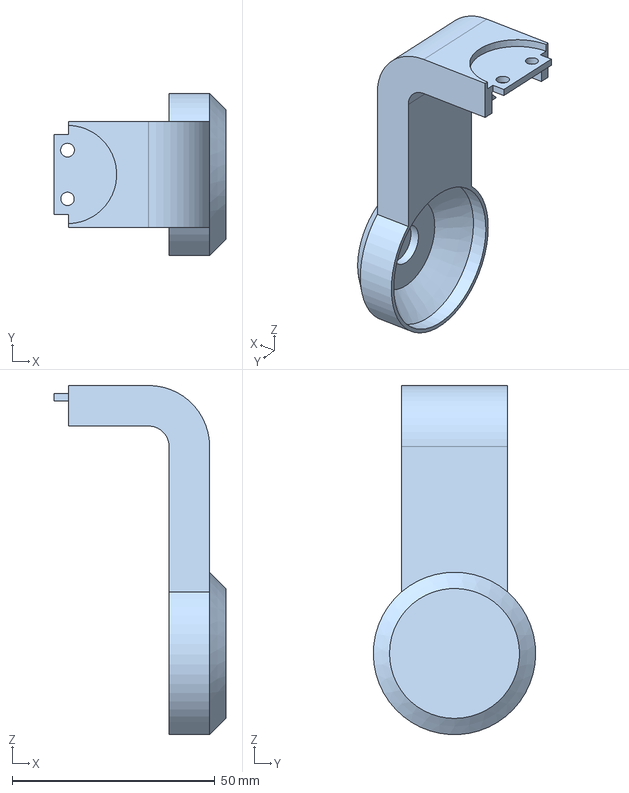
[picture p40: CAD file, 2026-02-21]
description/models/step/6x_motor_arm2.step
42.3 x 40.0 x 86.0 mm

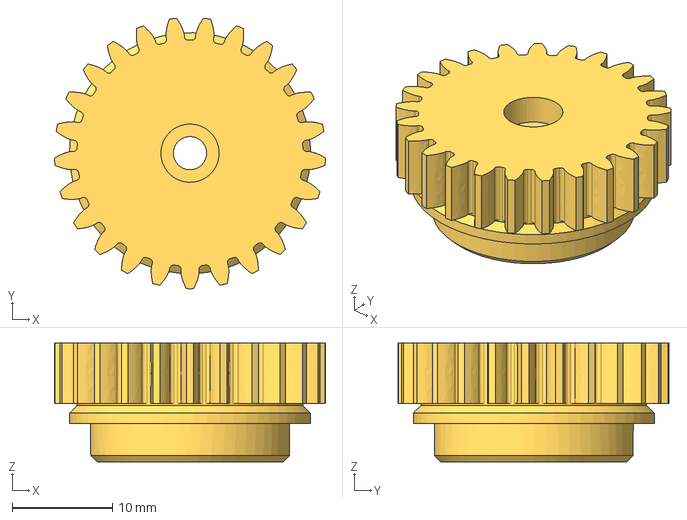
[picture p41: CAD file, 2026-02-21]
description/models/step/6x_gear.step
27.0 x 26.9 x 11.8 mm

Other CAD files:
description/models/stl/frame_left.stl
description/models/stl/frame_pt2.stl
description/models/stl/frame_right.stl
description/models/stl/frame_pt1.stl
description/models/step/12x_motor_mount.step
description/models/step/1x_1xm_top_arm_back.step
description/models/step/1x_1xm_top_arm_front.step
description/models/step/1x_frame.step
description/models/step/1x_top_front.step
description/models/step/6x_gear_servo.step
description/models/step/6x_rim.step
description/models/stl/12x_motor_mount.stl
description/models/stl/1x_1xm_pusher.stl
description/models/stl/1x_1xm_small_bevel_gear.stl
description/models/stl/1x_1xm_top_arm_back.stl
description/models/stl/1x_1xm_top_arm_coupler.stl
description/models/stl/1x_1xm_top_arm_front.stl
description/models/stl/1x_bottom.stl
description/models/stl/1x_differential_mount.stl
description/models/stl/1x_frame.stl
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

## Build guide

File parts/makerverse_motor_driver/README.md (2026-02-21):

https://core-electronics.com.au/makerverse-motor-driver-2-channel.html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

https://core-electronics.com.au/guides/raspberry-pi-pico/makerverse-motor-driver-2-channel-application-guide/

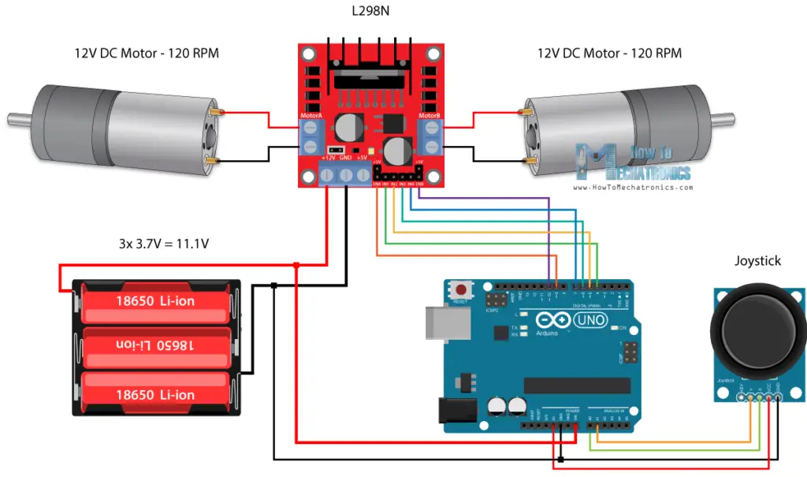
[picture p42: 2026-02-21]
parts/25GA370_dc_geared_motor/images/hookup_guide.webp

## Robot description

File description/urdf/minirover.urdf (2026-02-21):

<robot name="Fun_Robot">
  <link name="base_footprint"></link>
  <joint name="base_joint" type="fixed">
    <parent link="base_footprint" />
    <child link="base_link" />
    <origin xyz="0 0 1.0346219421912055" rpy="0 0 0" />
  </joint>
  <link name="base_link">
    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
    <inertial>
      <origin xyz="-0.1 0 0.9027520137700034" rpy="0 0 0" />
      <mass value="1" />
      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
    </inertial>
  </link>
  <joint name="base_link_to_lidar" type="fixed">
    <parent link="base_link" />
    <child link="lidar" />
    <origin xyz="0 0 0.2569669071788341" rpy="0 0 0" />
  </joint>
  <link name="lidar">
    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
    <inertial>
      <origin xyz="0 0 0" rpy="0 0 0" />
      <mass value="1" />
      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
    </inertial>

        <sensor type="lidar" name="lidar">
            <always_on>true</always_on>
            <update_rate>5</update_rate>
            <origin>0 0 0.2569669071788341 0 0 0</origin>
            <ray>
                <scan>
                    <horizontal>
                        <samples>360</samples>
                        <resolution>1</resolution>
                        <min_angle>0</min_angle>
                        <max_angle>6.28</max_angle>
                    </horizontal>
                    <range>
                        <min>0.12</min>
                        <max>3.5</max>
                        <resolution>0.015</resolution>
                    </range>
                </scan>
                <noise>
                    <type>gaussian</type>
                    <mean>0</mean>
                    <stddev>0.01</stddev>
                </noise>
            </ray>
        </sensor>
      </link>
  <joint name="base_link_to_camera" type="fixed">
    <parent link="base_link" />
    <child link="camera" />
    <origin xyz="1.1503781763455796 -0.02298885073006307 0.3695319117946291" rpy="0 0 0" />
  </joint>
  <link name="camera">
    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
    <inertial>
      <origin xyz="0 0 0" rpy="0 0 0" />
      <mass value="1" />
      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
    </inertial>

        <sensor name="front_camera" type="camera">
            <always_on>true</always_on>
            <update_rate>100</update_rate>
            <origin>1.1503781763455796 -0.02298885073006307 0.3695319117946291 0 0 0</origin>
            <camera>
                <horizontal_fov>1.3962634</horizontal_fov>
                <image>
                    <width>800</width>
                    <height>600</height>
                    <format>R8G8B8</format>
                </image>
                <clip>
                    <near>0.1</near>
                    <far>100</far>
                </clip>
                <noise>
                    <type>gaussian</type>
                    <mean>0.01</mean>
                </noise>
            </camera>
        </sensor>
      </link>
  <joint name="base_link_to_imu_sensor" type="fixed">
    <parent link="base_link" />
    <child link="imu_sensor" />
    <origin xyz="-1.1282184172017464 0.06064584319013511 0.17904669409114127" rpy="0 0 0" />
  </joint>
  <link name="imu_sensor">
    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
    <inertial>
      <origin xyz="0 0 0" rpy="0 0 0" />
      <mass value="1" />
      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
    </inertial>

        <sensor type="imu" name="imu">
            <always_on>true</always_on>
            <update_rate>100</update_rate>
            <origin>-1.1282184172017464 0.06064584319013511 0.17904669409114127 0 0 0</origin>
            <imu>
                <noise>
                    <type>gaussian</type>
                    <mean>0</mean>
                    <stddev>0</stddev>
                </noise>
            </imu>
        </sensor>
      </link>
  <joint name="base_link_to_rocker_left" type="fixed">
    <parent link="base_link" />
    <child link="rocker_left" />
    <origin xyz="0.38796174770676306 -0.8514434097789625 0.5178297359775021" rpy="0 0 0" />
  </joint>
  <link name="rocker_left">
    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
    <inertial>
      <origin xyz="-0.1 -0.19 -0.1" rpy="0 0 0" />
      <mass value="1" />
      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
    </inertial>
  </link>
  <joint name="rocker_left_to_bogie_left" type="fixed">
    <parent link="rocker_left" />
    <child link="bogie_left" />
    <origin xyz="-1.2696153520729918 -0.33532188294748144 -0.3528361912168103" rpy="0 0 0" />
  </joint>
  <link name="bogie_left">
    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
    <inertial>
      <origin xyz="0 -0.03 -0.05" rpy="0 0 0" />
      <mass value="1" />
      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
    </inertial>
  </link>
  <joint name="bogie_left_to_axle_front_left" type="fixed">
    <parent link="bogie_left" />
    <child link="axle_front_left" />
    <origin xyz="-0.8084875533382786 -0.018610342967948834 0.21880239608438656" rpy="0 0 0" />
  </joint>
  <link name="axle_front_left">
    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
    <inertial>
      <origin xyz="0 0 -0.75" rpy="0 0 0" />
      <mass value="1" />
      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
    </inertial>
  </link>
  <joint name="axle_front_left_to_wheel_front_left" type="continuous">
    <parent link="axle_front_left" />
    <child link="wheel_front_left" />
    <origin xyz="-0.028007632921228653 -0.007654303698455989 -0.9906135701380643" rpy="0 0 0" />
    <axis xyz="0 0 1"/>
  </joint>
  <link name="wheel_front_left">
    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
    <inertial>
      <origin xyz="0 0.01 0" rpy="0 0 0" />
      <mass value="1" />
      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
    </inertial>
  </link>
  <joint name="bogie_left_to_axle_middle_left" type="fixed">
    <parent link="bogie_left" />
    <child link="axle_middle_left" />
    <origin xyz="0.817890328003405 -0.011043711902632647 0.2262684297973403" rpy="0 0 0" />
  </joint>
  <link name="axle_middle_left">
    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
    <inertial>
      <origin xyz="0 0 -0.75" rpy="0 0 0" />
      <mass value="1" />
      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
    </inertial>
  </link>
  <joint name="axle_middle_left_to_wheel_middle_left" type="continuous">
    <parent link="axle_middle_left" />
    <child link="wheel_middle_left" />
    <origin xyz="-0.012394965507100397 -0.00479567704210071 -1.0069966421070031" rpy="0 0 0" />
    <axis xyz="0 0 1"/>
  </joint>
  <link name="wheel_middle_left">
    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
    <inertial>
      <origin xyz="0 0 0" rpy="0 0 0" />
      <mass value="1" />
      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
    </inertial>
  </link>
  <joint name="rocker_left_to_axle_back_left" type="fixed">
    <parent link="rocker_left" />
    <child link="axle_back_left" />
    <origin xyz="1.137334558980128 -0.33190400947322907 -0.1297027913657638" rpy="0 0 0" />
  </joint>
  <link name="axle_back_left">
    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
    <inertial>
      <origin xyz="0 0 -0.75" rpy="0 0 0" />
      <mass value="1" />
      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
    </inertial>
  </link>
  <joint name="axle_back_left_to_wheel_back_left" type="fixed">
    <parent link="axle_back_left" />
    <child link="wheel_back_left" />
    <origin xyz="-0.011927070052719535 -0.009841640964850296 -1.008057559272772" rpy="0 0 0" />
  </joint>
  <link name="wheel_back_left">
    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
    <inertial>
      <origin xyz="0 0.01 0" rpy="0 0 0" />
      <mass value="1" />
      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
    </inertial>
  </link>
  <joint name="base_link_to_rocker_right" type="fixed">
    <parent link="base_link" />
    <child link="rocker_right" />
    <origin xyz="0.3760131749123218 0.8579459580633835 0.5" rpy="0 0 0" />
  </joint>
  <link name="rocker_right">
    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
    <inertial>
      <origin xyz="0 0.19 -0.1" rpy="0 0 0" />
      <mass value="1" />
      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
    </inertial>
  </link>
  <joint name="rocker_right_to_bogie_right" type="fixed">
    <parent link="rocker_right" />
    <child link="bogie_right" />
    <origin xyz="-1.2825920049627044 0.3513262777408128 -0.322944345669941" rpy="0 0 0" />
  </joint>
  <link name="bogie_right">
    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
    <inertial>
      <origin xyz="0 0 -0.05" rpy="0 0 0" />
      <mass value="1" />
      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
    </inertial>
  </link>
  <joint name="bogie_right_to_axle_front_right" type="fixed">
    <parent link="bogie_right" />
    <child link="axle_front_right" />
    <origin xyz="-0.9280451515761341 -0.000585363195101607 -0.7792911535896829" rpy="0 0 0" />
  </joint>
  <link name="axle_front_right">
    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
    <inertial>
      <origin xyz="0.14 0 0.225" rpy="0 0 0" />
      <mass value="1" />
      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
    </inertial>
  </link>
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

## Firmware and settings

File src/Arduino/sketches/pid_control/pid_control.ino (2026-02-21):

/*
 * JGA25-370 Motor PID Control
 * 
 * This sketch implements PID control for the JGA25-370 DC geared motor
 * with integrated magnetic hall encoder for precise speed control.
 * 
 * Hardware:
 * - JGA25-370 DC Motor with encoder (6V variant recommended)
 * - L298N or TB6612FNG motor driver
 * - Arduino Nano/Uno/Mega
 * 
 * Connections:
 * - Motor Driver PWM -> Arduino PWM Pin (e.g., Pin 9)
 * - Motor Driver DIR1 -> Arduino Digital Pin (e.g., Pin 8)
 * - Motor Driver DIR2 -> Arduino Digital Pin (e.g., Pin 7)
 * - Encoder Channel A -> Arduino Interrupt Pin (e.g., Pin 2)
 * - Encoder Channel B -> Arduino Interrupt Pin (e.g., Pin 3)
 * 
 * Author: Artemis
 * License: MIT
 * Date: February 2026
 */

// Pin Definitions
const int MOTOR_PWM = 9;      // PWM pin for motor speed
const int MOTOR_DIR1 = 8;     // Direction pin 1
const int MOTOR_DIR2 = 7;     // Direction pin 2
const int ENCODER_A = 2;      // Encoder channel A (interrupt pin)
const int ENCODER_B = 3;      // Encoder channel B (interrupt pin)

// Motor Parameters
const int ENCODER_PPR = 12;   // Pulses per revolution (before gearing)
const float GEAR_RATIO = 46.8; // Gear ratio (check your motor specs)
const int ENCODER_CPR = ENCODER_PPR * GEAR_RATIO * 2; // Counts per revolution (quadrature)

// PID Parameters (tuned for JGA25-370, adjust as needed)
// Based on research: Kp ~ 2, Ki ~ 5, Kd ~ 1 for stable performance
float Kp = 2.0;               // Proportional gain
float Ki = 5.0;               // Integral gain
float Kd = 1.0;               // Derivative gain

// PID Variables
float setpoint = 0;           // Target speed in RPM
float input = 0;              // Current speed in RPM
float output = 0;             // PID output (PWM value)
float error = 0;              // Current error
float lastError = 0;          // Previous error
float integral = 0;           // Integral sum
float derivative = 0;         // Derivative term

// Speed Measurement Variables
volatile long encoderCount = 0;
long lastEncoderCount = 0;
unsigned long lastTime = 0;
const int SAMPLE_TIME = 100;  // Sample time in milliseconds

// Output limits
const int PWM_MIN = 0;
const int PWM_MAX = 255;
const float INTEGRAL_MAX = 1000; // Anti-windup limit

void setup() {
  // Initialize serial communication
  Serial.begin(115200);
  Serial.println("JGA25-370 PID Control Initialized");
  Serial.println("Commands: S<rpm> - Set speed, P<val> K<val> D<val> - Tune PID");
  
  // Configure motor driver pins
  pinMode(MOTOR_PWM, OUTPUT);
  pinMode(MOTOR_DIR1, OUTPUT);
  pinMode(MOTOR_DIR2, OUTPUT);
  
  // Configure encoder pins with pullup resistors
  pinMode(ENCODER_A, INPUT_PULLUP);
  pinMode(ENCODER_B, INPUT_PULLUP);
  
  // Attach interrupts for encoder
  attachInterrupt(digitalPinToInterrupt(ENCODER_A), encoderISR_A, CHANGE);
  attachInterrupt(digitalPinToInterrupt(ENCODER_B), encoderISR_B, CHANGE);
  
  // Initialize motor (stopped)
  setMotor(0, 1);
  
  lastTime = millis();
}

void loop() {
  // Check for serial commands
  handleSerialCommands();
  
  // Calculate speed at regular intervals
  unsigned long currentTime = millis();
  if (currentTime - lastTime >= SAMPLE_TIME) {
    // Calculate speed in RPM
    long encoderDelta = encoderCount - lastEncoderCount;
    float timeInterval = (currentTime - lastTime) / 1000.0; // Convert to seconds
    input = (encoderDelta / (float)ENCODER_CPR) * (60.0 / timeInterval); // RPM
    
    // Compute PID
    computePID();
    
    // Apply output to motor
    setMotor(output, (setpoint >= 0) ? 1 : -1);
    
    // Print status
    printStatus();
    
    // Update variables
    lastEncoderCount = encoderCount;
    lastTime = currentTime;
  }
}

void computePID() {
  // Calculate error
  error = setpoint - input;
  
  // Proportional term
  float P = Kp * error;
  
  // Integral term with anti-windup
  integral += error * (SAMPLE_TIME / 1000.0);
  if (integral > INTEGRAL_MAX) integral = INTEGRAL_MAX;
  if (integral < -INTEGRAL_MAX) integral = -INTEGRAL_MAX;
  float I = Ki * integral;
  
  // Derivative term
  derivative = (error - lastError) / (SAMPLE_TIME / 1000.0);
  float D = Kd * derivative;
  
  // Calculate total output
  output = P + I + D;
  
  // Constrain output
  output = constrain(abs(output), PWM_MIN, PWM_MAX);
  
  // Store error for next iteration
  lastError = error;
}

void setMotor(int pwmValue, int direction) {
  // Constrain PWM value
  pwmValue = constrain(abs(pwmValue), 0, 255);
  
  // Set direction
  if (direction > 0) {
    digitalWrite(MOTOR_DIR1, HIGH);
    digitalWrite(MOTOR_DIR2, LOW);
  } else if (direction < 0) {
    digitalWrite(MOTOR_DIR1, LOW);
    digitalWrite(MOTOR_DIR2, HIGH);
  } else {
    // Brake
    digitalWrite(MOTOR_DIR1, LOW);
    digitalWrite(MOTOR_DIR2, LOW);
  }
  
  // Set speed
  analogWrite(MOTOR_PWM, pwmValue);
}

// Encoder interrupt service routines
void encoderISR_A() {
  bool A = digitalRead(ENCODER_A);
  bool B = digitalRead(ENCODER_B);
  
  if (A == B) {
    encoderCount++;
  } else {
    encoderCount--;
  }
}

void encoderISR_B() {
  bool A = digitalRead(ENCODER_A);
  bool B = digitalRead(ENCODER_B);
  
  if (A != B) {
    encoderCount++;
  } else {
    encoderCount--;
  }
}

void handleSerialCommands() {
  if (Serial.available() > 0) {
    char cmd = Serial.read();
    float value = Serial.parseFloat();
    
    switch (cmd) {
      case 'S':
      case 's':
        setpoint = value;
        integral = 0; // Reset integral when changing setpoint
        Serial.print("Setpoint: ");
        Serial.print(setpoint);
        Serial.println(" RPM");
        break;
        
      case 'P':
      case 'p':
        Kp = value;
        Serial.print("Kp: ");
        Serial.println(Kp);
        break;
        
      case 'I':
      case 'i':
        Ki = value;
        Serial.print("Ki: ");
        Serial.println(Ki);
        integral = 0; // Reset integral when changing Ki
        break;
        
      case 'D':
      case 'd':
        Kd = value;
        Serial.print("Kd: ");
        Serial.println(Kd);
        break;
        
      case 'X':
      case 'x':
        setpoint = 0;
        integral = 0;
        Serial.println("Motor stopped");
        break;
        
      case '?':
        printHelp();
        break;
    }
  }
}

void printStatus() {
  Serial.print("Setpoint: ");
  Serial.print(setpoint);
  Serial.print(" | Speed: ");
  Serial.print(input);
  Serial.print(" | Error: ");
  Serial.print(error);
  Serial.print(" | Output: ");
  Serial.print(output);
  Serial.print(" | Count: ");
  Serial.println(encoderCount);
}

void printHelp() {
  Serial.println("\n=== PID Motor Control Commands ===");
  Serial.println("S<value> - Set target speed in RPM (e.g., S100)");
  Serial.println("P<value> - Set Kp gain (e.g., P2.5)");
  Serial.println("I<value> - Set Ki gain (e.g., I5.0)");
  Serial.println("D<value> - Set Kd gain (e.g., D1.2)");
  Serial.println("X        - Stop motor");
  Serial.println("?        - Show this help");
  Serial.println("==================================\n");
}

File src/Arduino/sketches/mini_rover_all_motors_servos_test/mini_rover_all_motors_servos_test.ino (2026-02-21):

/**
    Control 6 DC motors and 6 servos
*/
#include "PWMServo.h"

#define MAX_ACTUATORS 6
#define LED_INTERVAL_MS 500
#define STEP 10
#define SERVO_INTERVAL_MS 100

uint8_t motor_pwm_pins[MAX_ACTUATORS] = { 3, 4, 6, 8, 10, 12 };
uint8_t motor_dir_pins[MAX_ACTUATORS] = { 2, 5, 7, 9, 11, 24 };

PWMServo servos[MAX_ACTUATORS];
uint8_t servo_pins[MAX_ACTUATORS] = { 33, 36, 14, 15, 18, 19 };

bool is_sweeping = false;
bool increment = true;
int pos = 0;
byte state = 0;
unsigned long last_time = 0;
unsigned long servo_last_time = 0;
int servo_interval = SERVO_INTERVAL_MS;

void setup()
{
    Serial.begin(115200);
    delay(100);

    pinMode(LED_BUILTIN, OUTPUT);

    for(int i = 0; i < MAX_ACTUATORS; i++)
    {
        pinMode(motor_pwm_pins[i], OUTPUT);
        pinMode(motor_dir_pins[i], OUTPUT);
        servos[i].attach(servo_pins[i]);
    }
}

void position(int angle)
{
    for(int i = 0; i < MAX_ACTUATORS; i++){
        servos[i].write(angle);
    }

    Serial.print("angle: ");
    Serial.println(angle);
}

void sweep()
{
    unsigned long now = millis();

    if(now - servo_last_time > servo_interval)
    {
        servo_last_time = now;

        if(pos >= 180)
            increment = false;

        if(pos <= 0)
            increment = true;

        pos = increment ? pos + STEP :  pos - STEP;
        
        position(pos);
    }
}

void move()
{
    for(int i = 0; i < MAX_ACTUATORS; i++)
    {
        digitalWrite(motor_pwm_pins[i], HIGH);
        digitalWrite(motor_dir_pins[i], HIGH);

        delay(100);
    }
}

void move(int wheel)
{
    int idx = wheel - 1;
    
    digitalWrite(motor_pwm_pins[idx], HIGH);
    digitalWrite(motor_dir_pins[idx], HIGH);
}

void stop()
{
    for(int i = 0; i < MAX_ACTUATORS; i++)
    {
        digitalWrite(motor_pwm_pins[i], LOW);
        digitalWrite(motor_dir_pins[i], LOW);
    }

    is_sweeping = false;
}

void loop()
{
    if(Serial.available())
    {
        const char c = Serial.read();

        switch(c){
            case 's':
                is_sweeping = true;
                break;

            case 'a':
                is_sweeping = false;
                position(180);
                break;

            case 'w':
                is_sweeping = false;
                position(90);
                break;

            case 'd':
                is_sweeping = false;
                position(0);
                break;

            case 'e':
                move();
                break;

            case 'q':
                stop();
                break;

            case '=':
                servo_interval += 10;
                if(servo_interval > 500)
                    servo_interval = 500;
                Serial.print("Servo interval: "); Serial.println(servo_interval);
                break;

            case '-':
                servo_interval -= 10;
                if(servo_interval < 10)
                    servo_interval = 10;
                Serial.print("Servo interval: "); Serial.println(servo_interval);
                break;

            case '1':
                move(1);
                break;

            case '2':
                move(2);
                break;

            case '3':
                move(3);
                break;

            case '4':
                move(4);
                break;

            case '5':
                move(5);
                break;
            
            case '6':
                move(6);
                break;

            default:
                break;
        }
    }

    if(is_sweeping)
        sweep();

    unsigned long now = millis();

    if(now - last_time > LED_INTERVAL_MS){
        last_time = now;
        state = !state;
        digitalWrite(LED_BUILTIN, state);
    }
}

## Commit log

2026-02-21 add arduino language tag
2026-02-21 Fix: Exclude gcode and 3D models from language stats
    - Mark gcode files as linguist-vendored and linguist-generated
    - Mark all 3D model files as linguist-vendored
    - Properly tag Arduino sketches as Arduino/C++
    - Mark documentation files appropriately
2026-02-25 Fix: Configure language detection for C++
    - Mark .ino files as C++ for GitHub linguist
    - Ensure src/Arduino/** is detectable
    - Keep 3D models and vendor files excluded from stats
    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
